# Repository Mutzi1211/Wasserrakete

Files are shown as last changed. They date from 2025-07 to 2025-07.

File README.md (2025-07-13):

# 🚀 Projektstruktur: Wasserrakete

Ein Überblick über alle Projektbestandteile – von CAD über Code bis zu Anforderungen und Abgaben.

---

### 📁 Abgabe/Poster
- 📄 **Projekt 2 Plakatvorstellung A2.pdf**  
  ➤ Das Poster für die offizielle Projektpräsentation.
---

### 📁 cad
3D-Modelle und technische Zeichnungen zur Rakete.

- 📁 **Rakete**  
 ➤ Enthält die CAD-Dateien des Raketenmodells  
  ➤ Dient zur Fertigung 

- 📄 **Rakete.pdf**  
  ➤ Zeichnung für die Rakete
---

### 📁 code
Die komplette Firmware für den Datenlogger (ESP32, SD-Logging, Webserver etc.)

---

### 📁 pcb
Alle Dateien zur Platine für den Datenlogger.

- 📁 **data_logger**  
  ➤ PCB-Design, dass alles auf einer Platine ist. Leider nicht mehr fertig geworden, aber wichtig für die Reproduktion

- 📁 **Prototyp**  
  ➤ Aktuelle Stand. Zusammengesteckt aus verschiedenen Bauteilen und auf einem 3D-Druck Boden montiert.

  - 📄 **Schaltplan.pdf**  
  ➤ Aktueller Schaltplan 

- 📄 **PCB.pdf**  
  ➤ Visualisierung der geplanten PCBs. 

- 📄 **Schematic.pdf**  
 ➤ Schematic des geplanten PCBs.

---

### 📁 Requirement Engineering
Projektplanung, Funktionsdefinitionen und Anforderungen.

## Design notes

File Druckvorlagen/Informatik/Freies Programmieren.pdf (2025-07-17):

Informatik | Freies Programmieren.docx | 1

Variante 3: Freies Programmieren
Aufgabe: Baue einen Datenlogger mit automatischer Fallschirmauslösung
Du erhältst ein fertiges Hardware-Modul mit den folgenden Bauteilen:
Bauteil | Funktion | Schnittstelle Steuerung | Betriebsspannung | Besonderheiten

ESP32

ICM-20948

BME280

Servo

Schalter Taster

LCD – Display

Deine Aufgabe:
Du sollst ein Programm für den ESP32 entwickeln, das:
1. Die Höhe der Rakete misst,
2. Daten (Höhe, Temperatur, Beschleunigung) während des Flugs aufzeichnet,
3. automatisch einen Fallschirm auslöst
4. den Systemstatus auf dem Display zeigt.

So gehst du vor:
Recherche
- Fülle die Tabelle oben aus. Recherchiere für jedes Bauteil:
- Funktion (Was macht es?)
- Schnittstelle (Wie kommuniziert es mit dem ESP32 ?) Vorgehensweise:
- Teil die Arbeit auf mehr Schulter auf: jeder fängt mit einem Sensor an
- Einzelne Komponenten programmieren
- Programmteile testen
- Ergebnisse validieren
- Herangehensweisen vergleichen

- Beste ausarbeiten und auf anderen Sensoren adaptieren
- Zu einem großen Teil zusammenführen
Sensoren testen
- In PlatformIO ein neues Projekt erstellen.
- Bibliotheken einbinden (z. B. SparkFun_BME280, ICM_20948, ServoESP32).
- Teste, ob die Sensoren Werte liefern.
Datenlogger programmieren
- Schreibe ein Programm, das Höhe, Temperatur und Beschleunigung regelmäßig misst.
- Speichere die Werte im CSV-Format auf der SD-Karte
Fallschirmauslösung
- Überwache den Höhenverlauf.
- Wie kann der perfekte Punkt zum Auslösen bestimmt werden? Display-Ausgabe
- Zeige z. B. aktuelle Höhe, Temperatur und Status ("Ready", "Recording", "Fallschirm ausgelöst") an.
Tests und Validierung
- Teste dein System am Boden und überprüfe:
- Löst der Fallschirm zuverlässig aus?
- Werden die Daten sinnvoll und im richtigen Format aufgezeichnet?
- Sind die Sensorwerte plausibel?
Hinweise:
- Verwende eine saubere setup()- und loop()-Struktur.
- Kapsle komplexe Funktionen (z. B. checkParachuteTrigger()).
- Kommentiere deinen Code verständlich.
- Denke an Sicherheit: Fallschirm darf nicht sich nicht zu früh oder zu spät öffnen
- ChatGPT oder andere KI-Modelle können helfen den Code zu kontrollieren oder bei Fehlern zu helfen – verwende sie nicht um das gesamte Problem zu lösen, sondern lass nur Teile programmieren

## Testen des Moduls

Nehmt euch das fertige Modul und überprüft, ob es wie gewünscht funktioniert. Beobachtet dabei insbesondere den Moment der Auslösung: Öffnet sich der Fallschirm genau dann, wenn ihr es erwartet habt? Überlegt euch mögliche Ursachen, wenn das Modul zu früh oder zu spät auslöst. Mögliche Fehlerquellen könnten sein:
- Ungenaue Sensordaten (z. B. Rauschen oder Verzögerungen)
- Fehlerhafte Berechnung der Höhe oder des Höhenabfalls
- Falsche Referenzwerte im Code
- Verzögerungen durch den Servo
Testet außerdem die Datenaufzeichnung auf der SD-Karte:
- Ist das Format korrekt? (z. B. CSV mit Kommas oder Semikolon getrennt)
- Stimmen die Einheiten? (z. B. Meter für Höhe, °C für Temperatur, hPa für Luftdruck)
- Sind die Messwerte in einer sinnvollen Größenordnung? (z. B. keine negativen Höhenwerte oder unrealistisch hohe Temperaturen)
Versucht, die aufgezeichneten Daten zu validieren:
- Ist der Verlauf der Höhe plausibel? Gibt es z. B. einen klar erkennbaren Anstieg beim Start und einen Abfall nach der höchsten Stelle?
- Entsprechen die Temperaturwerte etwa der Umgebungstemperatur?
- Verhält sich der Luftdruck physikalisch korrekt (z. B. sinkender Druck mit zunehmender Höhe)?
Diese Tests helfen euch, mögliche Fehler frühzeitig zu erkennen und die Funktion eures Systems zu verbessern.

## Aufzeichnen der Flugdaten

Für die Test empfehlen wir die Finnen 1 und die ogive Spitze. Die Flasche sollte mit 500ml Wasser gefüllt sein und bis 5 bar Luftdruck.
Jetzt wird’s spannend: Deine Rakete ist bereit für den Start – und dein Messmodul soll alle wichtigen Daten aufzeichnen! Höhe, Luftdruck, Temperatur und Bewegung geben dir spannende Einblicke in den Flugverlauf. Mit diesen Daten kannst du später genau analysieren, wann der höchste Punkt erreicht wurde, wie schnell die Rakete steigt – und ob der Fallschirm im richtigen Moment ausgelöst wurde.
Genaue Startanleitung in Plug-and-Play.
Hier ein Tutorial, wie man den Fallschirm richtig faltet, dass er
zuverlässig aufgeht.
https://www.youtube.com/shorts/kGTpw6yevmc?feature=share

Sicherheitshinweise
Bevor du mit dem Start beginnst, beachte folgende Punkte:
- Luftpumpe prüfen: Achte darauf, dass die Luftpumpe einen genau Anzeige hat. Die 5 Bar dürfen nicht überschritten werden.
- Zustand der Flasche prüfen: nach einigen Flügen können sich Risse am Hals der Flasche bilden. Außerdem wird die Flasche zunehmend dünner. Wechsle die Flasche nach 10 Starts aus.
- Sicherheitsabstand einhalten: Alle Zuschauer und Beteiligten müssen beim Start mindestens 5 m Abstand halten.
- Schutzbrille tragen: Bei Arbeiten mit Druckluft ist eine Schutzbrille Pflicht.
- Modul richtig befestigen: Das Modul muss mit der Flasche stabil verklebt sein, da diese sonst getrennt herunterfallen könnten.
- Startrampe nur auf freiem Gelände verwenden: Kein Start in der Nähe von Gebäuden, Straßen oder Stromleitungen. Empfehlung hierzu ist einer der kurzen Seiten eines Sportplatzes und leicht in die andere Richtung ausrichten. (maximal 20 Grad von der Senkrechten)
- Nie auf Menschen oder Tiere zielen: Die Rakete ist kein Spielzeug!
- Niemals die Rakete versuchen zu fangen.

## Analyse der Daten

Aufgabe: Auswertung der Flugdaten mit Excel
Für die Auswertung der Daten könnt euch für das Programm eure Wahl entscheiden. Bei Vorerfahrung kann Python mit dem Modul MathPlotLib eine Möglichkeit sein. Für den ersten Umgang mit Daten empfiehlt sich Excel.
Auswertung mit Excel:
1. CSV-Datei öffnen
- Starte Excel
- Öffne deine log_XXXX.csv-Datei
- Spaltenüberschriften umbenennen:
- Zeit [s], Höhe [m], Beschleunigung [g], Luftdruck [hPa], Temperatur [°C] etc
- Achte auf richtige Schreibweise (Excel verwendet Kommas für die Nachkommastellen, in der CSV Datei sind es Punkte – das Tool Suchen und Ersetzten kann helfen)
2. Höhe über Zeit – Diagramm erstellen
- Spalten „Zeit [s]“ und „Höhe [m]“ markieren
- Einfügen → Liniendiagramm
- Flugverlauf sichtbar machen
Arbeite aus den Daten folgende Wert heraus.
- Höchste Beschleunigung
- Apogäum
- Flugdauer
- Maximale Geschwindigkeit
- Sinkgeschwindigkeit
- Kann man daraus die Formel für den Senkrechten Wurf ausarbeiten?
- Bestimme den c_w Wert des Fallschirms (Masse, Luftdichte und Fläche gegeben)
- Bestimme die Schubkurve Wasserrakete – wie unterscheidet sie schon von großen Raketen bzw. Modellraketen mit Schwarzpulvermotor

## Daten präsentieren

Nachdem du deine Flugdaten ausgewertet hast, geht es nun darum, die Ergebnisse klar und verständlich darzustellen. Eine gute Präsentation hilft dabei, deine Messungen nachvollziehbar zu machen und besondere Erkenntnisse hervorzuheben. Übersichtliche Darstellung
- Erstelle eine strukturierte Auswertung in Excel oder PowerPoint.
- Nutze Tabellen für Werte wie Apogäum, Flugdauer, Maximalgeschwindigkeit etc.
- Verwende Diagramme, z. B.:
- Höhe über Zeit (für Flugkurve)
- Geschwindigkeit über Zeit
- Schubkurve
- Beschleunigung über Zei
Hebe Besonderheiten hervor
- Zeige deutlich, wo das Apogäum liegt
- Benenne Stellen mit besonderer Beschleunigung oder auffälligem Flugverhalten.
- Wenn der Fallschirm ausgelöst wurde: Markiere diesen Zeitpunkt (z. B. durch eine vertikale Linie im Diagramm).
- Was ist bei euren Daten besonders
- Gab es Probleme bei der Auswertung
Wenn jede Gruppe die gleichen Daten vorstellt, kann es schnell langweilig werden. Konzentriert euch auf die Erfolge oder Probleme, die ihr das Projekt hinweg hattet. Interpretation
Erkläre mit eigenen Worten:
- Was passiert wann?
- Warum sieht die Kurve so aus?
- Welche Phase des Flugs erkennst du (Start, Steigflug, Apogäum, Sinkflug)?
- Vergleiche berechnete Werte mit theoretischen Erwartungen (z. B. Höhe beim senkrechten Wurf).
Kreative Präsentationsform
- Erstelle ein kurzes Poster, ein Video mit Flug- und Datenanalyse oder einen digitalen Bericht.
- Baue Screenshots deiner Diagramme ein.
- Ergänze ein Fazit: Was würdest du beim nächsten Mal anders machen?
Ziel ist nicht nur, die Daten zu zeigen – sondern auch zu erklären, was sie bedeuten und was du daraus gelernt hast.

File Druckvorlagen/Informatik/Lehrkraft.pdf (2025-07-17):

Informatik | 1

## Informatik

## Programmierung:

Die Programmierung des Lernkoffers kann je nach Schulumgebung, Vorerfahrung der Schülerinnen und Schüler sowie verfügbarer Zeit im Unterricht auf drei unterschiedlichen Niveaus erfolgen. Jedes Niveau verfolgt ein eigenes Lernziel und adressiert unterschiedliche Kompetenzbereiche.
1. Plug-and-Play – Einstieg ohne Programmierkenntnisse
Zielgruppe:
Schülerinnen und Schüler ohne Vorerfahrung in der Programmierung.
Ausstattung:
Der Lernkoffer ist vollständig vorinstalliert. Beim Einschalten durchläuft der Bordcomputer automatisch einen Startprozess, bei dem alle Sensoren initialisiert und die Datenerfassung gestartet wird.
Mögliche Aufgabenstellungen:
- Beobachtung des Systemverhaltens: Welche Daten werden erfasst?
- Interpretation von Sensordaten im Webinterface (z. B. Beschleunigung, Höhe, Spannung)
- Exportieren und Auswerten der CSV-Daten am PC (z. B. in Excel, LibreOffice oder Python)
- Verständnisfragen: Was ist ein Sensor? Wie funktioniert ein Mikrocontroller?
- Physikalische Einordnung der Werte (z. B. Luftdruck ↔ Höhe)
Lernziele:
- Erste Begegnung mit digitalen Messsystemen
- Grundverständnis für Datenverarbeitung und Datenauswertung
- Förderung der Medienkompetenz ohne Einstieg in Programmiersyntax
2. Programmierung mit Unterstützung – Geführtes Lernen mit PlatformIO
Zielgruppe:
Schülerinnen und Schüler mit ersten Programmiererfahrungen oder technikaffine Gruppen.
Ausstattung:
Rechner mit Visual Studio Code (VS Code) und der PlatformIO-Erweiterung. Das Projekt wird bereitgestellt und kann geöffnet, angepasst und wieder auf den ESP32 hochgeladen werden.

Typische Inhalte und Aufgaben:
- Methoden anpassen: z. B. triggerParachute() nur bei bestimmtem Höhenabfall
- Sensorwerte filtern oder glätten (Moving Average, Schwellenwert)
- Neue Webinterface-Befehle implementieren (z. B. „Start Aufnahme“)
- LED oder Display-Ausgabe hinzufügen
- Logik für Messungen ändern (z. B. kürzere Intervalle, Schwellenwerte dynamisch setzen)
Lernziele:
- Verstehen von Methoden, Variablen und Bedingungen in C++
- Umgang mit Entwicklungsumgebungen (VS Code + PlatformIO)
- Erweitern bestehender Programme um eigene Ideen
- Teamarbeit beim Entwickeln und Testen
3. Selbst Programmieren – Freies Projekt für Fortgeschrittene
Zielgruppe:
Leistungsstarke oder besonders motivierte Schülerinnen und Schüler mit umfangreicher Vorerfahrung oder im Rahmen von Wahlkursen / Projekttagen.
Ausstattung:
Beliebige Entwicklungsumgebung (PlatformIO, Arduino IDE oder andere), Internetzugang zur Recherche.
Anforderungen:
- Selbständige Initialisierung der Sensoren über I2C/SPI
- Nutzung und Einbindung passender Bibliotheken (z. B. Adafruit, SparkFun)
- Strukturierung eines eigenen Programms: setup(), loop(), Klassenbildung
- Logging auf SD-Karte, Webinterface, OTA-Update (je nach Zielsetzung) Mögliche Projekte:
- Raketenflug vollständig selbst messen und analysieren
- Dashboards in Echtzeit gestalten
- Datenauswertung mit Python oder in der Cloud
- Kombination mehrerer Sensoren (z. B. BME280 + ICM20948) Lernziele:
- Selbstorganisiertes und forschendes Lernen
- Anwendung fortgeschrittener Programmierkonzepte
- Verstehen von Kommunikationsprotokollen und Datenformaten
- Problemlösestrategien und Debugging

Hinweis für Lehrkräfte:
Alle drei Stufen können auch parallel in einer Lerngruppe stattfinden. Die Lernkoffer bieten genug Flexibilität, um unterschiedliche Anforderungsniveaus zu bedienen und individuelle Lernpfade zu ermöglichen.

Hier ein Tutorial, wie man den Fallschirm richtig faltet, dass er zuverlässig aufgeht.
https://www.youtube.com/shorts/kGTpw6yevmc?feature=share

Eine genaue Startanleitung ist in „Plug-and-Play“ beschrieben.
Ansonsten gibt es eine kurze Videoanleitung unter: https://www.youtube.com/watch?v=_mfvzam6YKM&ab_channel=RaketfuedRockets

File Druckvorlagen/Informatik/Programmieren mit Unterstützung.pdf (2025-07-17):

Informatik | Programmieren mit Unterstützung.docx | 1

Variante 2: Programmierung mit Unterstützung
1. Überblick & Zielsetzung
Ziel:
Die Schüler entwickeln ein eigenes Programm für den Bordcomputer. Dieser soll:
- Sensordaten als Datenlogger aufzeichnen
- Bei Bedarf den Fallschirm auslösen
2. Komponenten verstehen
Verschaffe dir einen Überblick über alle Bauteile des Moduls. Nutze dazu den vereinfachten Schaltplan.
3. Rechercheaufgabe
In der Informatik kommunizieren Bauteile über sogenannte Schnittstellen (Interfaces). Um herauszufinden, wie die Sensoren funktionieren und wie man sie ansteuert, hilft eine gezielte Online-Recherche (z. B. mit den Begriffen „ESP32“ oder „Arduino“). Fülle die folgende Tabelle aus, indem du die Funktionen und Eigenschaften der Bauteile recherchierst:
Bauteil | Funktion | Schnittstelle Steuerung | Betriebsspannung | Besonderheiten

ESP32

ICM-20948

BME280

Servo

Schalter Taster

LCD – Display

Tipp: Oft hilft es, bei der Recherche Begriffe wie „ESP32“ oder „Arduino“ zu verwenden.

4. Schnittstellen & Spannungen verstehen
Initialisierung von Bauteilen – Warum ist das wichtig?
Bevor ein Mikrocontroller wie der ESP32 mit angeschlossenen Bauteilen arbeiten kann
(z. B. Sensoren, Servos oder Schalter), müssen diese im Programm initialisiert werden. Das bedeutet:
- Die Verbindung zwischen Mikrocontroller und Bauteil wird im Code festgelegt.
- Die Kommunikationseinstellungen (z. B. über welche Schnittstelle kommuniziert wird) werden definiert.
- Es wird geprüft, ob das Bauteil erkannt und funktionsfähig ist.
Warum ist das notwendig?
Ohne diese Initialisierung „weiß“ der ESP32 nicht, welches Gerät angeschlossen ist oder wie er mit diesem kommunizieren soll. Es ist vergleichbar mit einem Gerät, das angeschlossen wurde, aber nicht eingeschaltet oder konfiguriert wurde.
Was sind Schnittstellen?
Schnittstellen (auch „Interfaces“ genannt) sind digitale Verbindungsmöglichkeiten, über die zwei Geräte Daten austauschen können.
Wichtige Schnittstellen auf dem ESP32:
- I²C: Eine Bus-Schnittstelle für viele Sensoren über nur zwei Leitungen (SDA & SCL)
- SPI: Schnelle serielle Schnittstelle, ideal für SD-Karten oder Displays
- GPIO: Allgemeine Ein-/Ausgänge, z. B. für Taster, LEDs oder einfache Sensoren
- PWM: Pulsweitenmodulation – wird z. B. für Servos oder Helligkeitssteuerung genutzt

Beispiel: Der Sensor BME280 nutzt I²C – dafür muss man im Code angeben, an welchen Pins SDA (Datenleitung) und SCL (Taktleitung) angeschlossen sind.

Typische Spannungen:
- 3,3 V: Die meisten Sensoren für den ESP32
- 5,0 V: Häufig bei Arduino Uno oder bei Servos
Achtung: Der ESP32 arbeitet intern mit 3,3 V. Bauteile, die mit 5 V kommunizieren, brauchen oft einen Pegelwandler!
Zusammengefasst:
- Initialisierung: Der ESP32 muss wissen, welches Gerät da ist und wie man es anspricht.

- Schnittstellen: Jede Bauteilart spricht eine eigene Sprache (z. B. I²C, SPI, PWM…)
- Spannung: Zu hohe Spannung zerstört Bauteile – zu wenig Spannung verhindert Funktion
5. Programmaufbau verstehen
Der ESP32 führt Programme in einer festen Reihenfolge aus.
Er startet immer mit: | Dann läuft dauerhaft:

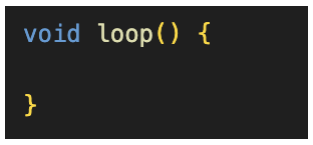
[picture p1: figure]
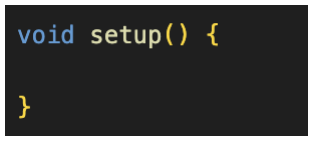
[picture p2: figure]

Zur Erleichterung sind bereits Bereiche vordefiniert, die zu bestimmten Zeitpunkten aufgerufen werden. (Sind mit Kommentaren markiert)
Typischer Aufbau:
Programmbereich | Aufgabe
setup() | Einmalige Aufgaben Komponenten initialisieren (.init() Methoden)
loop() | Wiederkehrende Aufgaben Daten aufzeichnen, Fallschirm-Bedingung prüfen
6. Klassendiagramm & Methoden
Alle Sensoren sind als Klassen implementiert. Die Methoden zur Initialisierung und Abfrage sind standardisiert.
Hinweis: Initialisierungen geben einen booleschen Wert zurück (true bei Erfolg). Beispielmethoden:
- bool initSensor()
- float getAltitude()
- bool initWebserver()
7. Erweiterung: Webinterface
Optional kann der ESP32 eine Webseite bereitstellen, um Live-Daten anzuzeigen. Dafür wird die Methode initWebserver() verwendet.

8. Programmablauf planen
Erstelle ein Flussdiagramm, das den Ablauf deines Programms beschreibt.
Dein Auftrag:
- Entwickle allein ein Flussdiagramm zum Ablauf eures Raketenprogramms.
- Tauscht euch danach in der Gruppe aus.
- Diskutiert Vor- und Nachteile eurer Lösungen.
Als Beispiel für ein Flussdiagramm hier ein potenzieller Ablauf von Spaghetti essen.
9. Diskussionspunkte

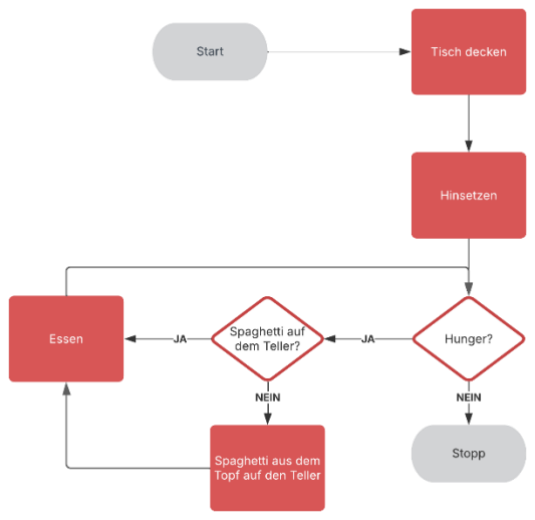
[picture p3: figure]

- Was passiert, wenn ein Sensor nicht erkannt wird?
- Was, wenn die SD-Karte fehlt oder voll ist?
- Wie könnt ihr Fehler erkennen und melden?
10. Umsetzung auf dem ESP32
Lade das Programm über PlatformIO auf den ESP32. Arbeite nur in der Datei main.cpp (im src-Ordner). Verwende ausschließlich die vordefinierten Methoden. (s. letztes Blatt)
11. Wie wird der Fallschirm ausgelöst?
Entscheide dich für eine oder mehrere Bedingungen:
- Höhenabfall größer als X m?
- Hohe Beschleunigung?
- Drehbewegung (Gyroskop)?
→ entwickle ein detailliertes Flussdiagramm für die Fallschirmauslösung (Vorschlag auf der nächsten Seite)

Vergleicht euer Ergebnis mit dem Vorschlag. Stellt Vor- Nachteile eure Lösung im Vergleich zum Vorschlag dar. Ein paar weiter Diskussionspunkte:
- Warum mehr als 0.1 Meter unter höchster Höhe
- Warum 10 Sekunden warten?
- Warum die Gesamt-beschleunigung?
- Wo würde man einfügen die geflogene Höhe auf dem Display anzuzeigen?
12. Anschluss & Verdrahtung

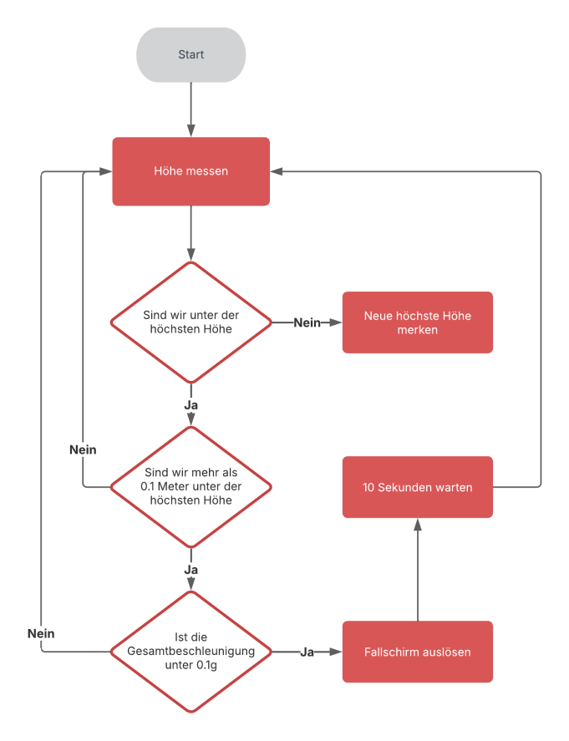
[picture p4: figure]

Nutze den Schaltplan, um die Pinbelegung nachzuvollziehen.
Die richtige Verdrahtung ist Voraussetzung für eine funktionierende Programmierung.

## Testen des Moduls

Nehmt euch das fertige Modul und überprüft, ob es wie gewünscht funktioniert. Beobachtet dabei insbesondere den Moment der Auslösung: Öffnet sich der Fallschirm genau dann, wenn ihr es erwartet habt? Überlegt euch mögliche Ursachen, wenn das Modul zu früh oder zu spät auslöst. Mögliche Fehlerquellen könnten sein:
- Ungenaue Sensordaten (z. B. Rauschen oder Verzögerungen)
- Fehlerhafte Berechnung der Höhe oder des Höhenabfalls
- Falsche Referenzwerte im Code
- Verzögerungen durch den Servo
Testet außerdem die Datenaufzeichnung auf der SD-Karte:
- Ist das Format korrekt? (z. B. CSV mit Kommas oder Semikolon getrennt)
- Stimmen die Einheiten? (z. B. Meter für Höhe, °C für Temperatur, hPa für Luftdruck)
- Sind die Messwerte in einer sinnvollen Größenordnung? (z. B. keine negativen Höhenwerte oder unrealistisch hohe Temperaturen)
Versucht, die aufgezeichneten Daten zu validieren:
- Ist der Verlauf der Höhe plausibel? Gibt es z. B. einen klar erkennbaren Anstieg beim Start und einen Abfall nach der höchsten Stelle?
- Entsprechen die Temperaturwerte etwa der Umgebungstemperatur?
- Verhält sich der Luftdruck physikalisch korrekt (z. B. sinkender Druck mit zunehmender Höhe)?
Diese Tests helfen euch, mögliche Fehler frühzeitig zu erkennen und die Funktion eures Systems zu verbessern.

## Aufzeichnen der Flugdaten

Für die Test empfehlen wir die Finnen 1 und die ogive Spitze. Die Flasche sollte mit 500ml Wasser gefüllt sein und bis 5 bar Luftdruck.
Jetzt wird’s spannend: Deine Rakete ist bereit für den Start – und dein Messmodul soll alle wichtigen Daten aufzeichnen! Höhe, Luftdruck, Temperatur und Bewegung geben dir spannende Einblicke in den Flugverlauf. Mit diesen Daten kannst du später genau analysieren, wann der höchste Punkt erreicht wurde, wie schnell die Rakete steigt – und ob der Fallschirm im richtigen Moment ausgelöst wurde.
Genaue Startanleitung in Plug-and-Play.
Hier ein Tutorial, wie man den Fallschirm richtig faltet, dass er
zuverlässig aufgeht.
https://www.youtube.com/shorts/kGTpw6yevmc?feature=share

Sicherheitshinweise
Bevor du mit dem Start beginnst, beachte folgende Punkte:
- Luftpumpe prüfen: Achte darauf, dass die Luftpumpe einen genau Anzeige hat. Die 5 Bar dürfen nicht überschritten werden.
- Zustand der Flasche prüfen: nach einigen Flügen können sich Risse am Hals der Flasche bilden. Außerdem wird die Flasche zunehmend dünner. Wechsle die Flasche nach 10 Starts aus.
- Sicherheitsabstand einhalten: Alle Zuschauer und Beteiligten müssen beim Start mindestens 5 m Abstand halten.
- Schutzbrille tragen: Bei Arbeiten mit Druckluft ist eine Schutzbrille Pflicht.
- Modul richtig befestigen: Das Modul muss mit der Flasche stabil verklebt sein, da diese sonst getrennt herunterfallen könnten.
- Startrampe nur auf freiem Gelände verwenden: Kein Start in der Nähe von Gebäuden, Straßen oder Stromleitungen. Empfehlung hierzu ist einer der kurzen Seiten eines Sportplatzes und leicht in die andere Richtung ausrichten. (maximal 20 Grad von der Senkrechten)
- Nie auf Menschen oder Tiere zielen: Die Rakete ist kein Spielzeug!
- Niemals die Rakete versuchen zu fangen.

## Analyse der Daten

Aufgabe: Auswertung der Flugdaten mit Excel
Für die Auswertung der Daten könnt euch für das Programm eure Wahl entscheiden. Bei Vorerfahrung kann Python mit dem Modul MathPlotLib eine Möglichkeit sein. Für den ersten Umgang mit Daten empfiehlt sich Excel.
Auswertung mit Excel:
1. CSV-Datei öffnen
- Starte Excel
- Öffne deine log_XXXX.csv-Datei
- Spaltenüberschriften umbenennen:
- Zeit [s], Höhe [m], Beschleunigung [g], Luftdruck [hPa], Temperatur [°C] etc
- Achte auf richtige Schreibweise (Excel verwendet Kommas für die Nachkommastellen, in der CSV Datei sind es Punkte – das Tool Suchen und Ersetzten kann helfen)
2. Höhe über Zeit – Diagramm erstellen
- Spalten „Zeit [s]“ und „Höhe [m]“ markieren
- Einfügen → Liniendiagramm
- Flugverlauf sichtbar machen
Arbeite aus den Daten folgende Wert heraus.
- Höchste Beschleunigung
- Apogäum
- Flugdauer
- Maximale Geschwindigkeit
- Sinkgeschwindigkeit
- Kann man daraus die Formel für den Senkrechten Wurf ausarbeiten?
- Bestimme den c_w Wert des Fallschirms (Masse, Luftdichte und Fläche gegeben)
- Bestimme die Schubkurve Wasserrakete – wie unterscheidet sie schon von großen Raketen bzw. Modellraketen mit Schwarzpulvermotor

## Daten präsentieren

Nachdem du deine Flugdaten ausgewertet hast, geht es nun darum, die Ergebnisse klar und verständlich darzustellen. Eine gute Präsentation hilft dabei, deine Messungen nachvollziehbar zu machen und besondere Erkenntnisse hervorzuheben. Übersichtliche Darstellung
- Erstelle eine strukturierte Auswertung in Excel oder PowerPoint.
- Nutze Tabellen für Werte wie Apogäum, Flugdauer, Maximalgeschwindigkeit etc.
- Verwende Diagramme, z. B.:
- Höhe über Zeit (für Flugkurve)
- Geschwindigkeit über Zeit
- Schubkurve
- Beschleunigung über Zeit
Hebe Besonderheiten hervor
- Zeige deutlich, wo das Apogäum liegt
- Benenne Stellen mit besonderer Beschleunigung oder auffälligem Flugverhalten.
- Wenn der Fallschirm ausgelöst wurde: Markiere diesen Zeitpunkt (z. B. durch eine vertikale Linie im Diagramm).
- Was ist bei euren Daten besonders
- Gab es Probleme bei der Auswertung
Wenn jede Gruppe die gleichen Daten vorstellt, kann es schnell langweilig werden. Konzentriert euch auf die Erfolge oder Probleme, die ihr das Projekt hinweg hattet. Interpretation
Erkläre mit eigenen Worten:
- Was passiert wann?
- Warum sieht die Kurve so aus?
- Welche Phase des Flugs erkennst du (Start, Steigflug, Apogäum, Sinkflug)?
- Vergleiche berechnete Werte mit theoretischen Erwartungen (z. B. Höhe beim senkrechten Wurf).
Kreative Präsentationsform
- Erstelle ein kurzes Poster, ein Video mit Flug- und Datenanalyse oder einen digitalen Bericht.
- Baue Screenshots deiner Diagramme ein.
- Ergänze ein Fazit: Was würdest du beim nächsten Mal anders machen?
Ziel ist nicht nur, die Daten zu zeigen – sondern auch zu erklären, was sie bedeuten und was du daraus gelernt hast.

Methoden

Methoden | Funktion
init() | Starte die Protokolle für SD-Karte und Sensoren
initWebserver() | Starte Webserver und WLAN
initRecording() | Legt die CSV - Datei an
record() | Legt die aktuellen Werte auf der SD-Karte ab
check_parachute() | Gibt true zurück, wenn der Fallschirm auslösen soll
deploy_parachute() | Löst den Pin für Fallschirm aus Sollte wieder eingefahren werden
stop_parachute() | Fährt den Pin des Fallschirms wieder aus
reset() | Setzt die Daten für die Fallschirmauslösung zurück

Alle Komponenten müssen mit .init() aufgerufen werden und deren Status in die dazugehörige Variable gespeichert werden.
Bsp:
bme_active = bme.init();

Dies gilt für:
- icm
- bme
- lipo
- oled
- servo

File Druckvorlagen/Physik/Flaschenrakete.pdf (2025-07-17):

Physik | Flaschenrakete.docx | 1

# Aufbau der Flaschenrakete

## Grundprinzip Aerodynamik (Schwerpunkt & Druckpunkt):

Die Aerodynamik kleiner Raketen (z. B. Modellraketen) beruht im Wesentlichen auf dem Zusammenspiel von Schwerpunkt (Massenmittelpunkt der Rakete) und Druckpunkt (Angriffspunkt der resultierenden aerodynamischen Kräfte). Diese bestimmen die Flugstabilität.

Eine Passive Flugstabilisierung ist bei jeder Rakete anzustreben. Dies ist gegeben, sobald der Schwerpunkt in Flugrichtung vor dem Druckpunkt liegt. Der Abstand zwischen SP und DP sollte ca. 1– 2 Kaliber (Raketendurchmesser) betragen.

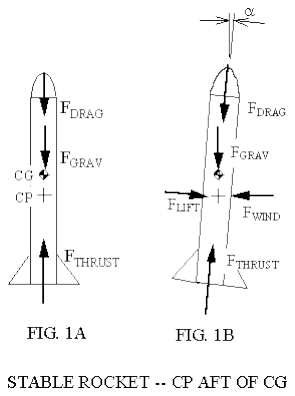
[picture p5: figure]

## Warum Finnen?

Generell funktionieren Finnen, indem sie, wenn die Rakete leicht von der Flugrichtung abweicht, ein Luftstrom schräg auf die Finnen trifft. Dies erzeugt eine aerodynamische Rückstellkraft um den Schwerpunkt, welche der Störung entgegenwirkt.

Wir nutzen Finnen am Ende der Rakete, selbst mit einer Passiven Stabilisierung, um die Flugbahn auch in dem Bereich des Fluges kontrolliert zu halten, der für eine passive Stabilisierung durch Schwerpunkt und Druckpunkt noch nicht schnell genug ist, bzw. nicht genug Luftstrom bietet.

Abbildung 1: Stable Rocket
Quelle: https://antwortenhier.me/q/stabilitaet-der-rakete-waehrend-des-fluges-warum-aendert-die-auftriebskraft-143452964425

## Wie viele Finnen?

Weniger als drei Finnen bieten keine vollständige seitliche Abdeckung und führen zu Instabilität oder unkontrollierter Rollbewegung. Mehr als drei, etwa vier oder fünf Finnen, abgesehen der höheren Massenkalkulation, erhöhen den Luftwiderstand deutlich, was zu einem geringeren Apogäum führt und die Effizienz verschlechtert. Außerdem verlagern zusätzliche Finnen den Massenschwerpunkt weiter nach hinten, was die Stabilitätsreserve reduziert, wenn nicht durch zusätzliches Frontgewicht kompensiert wird.

## Aerodynamik Spitzenformen

Die Form der Raketenspitze hat großen Einfluss auf die Aerodynamik, insbesondere auf den Luftwiderstand und das Flugverhalten bei unterschiedlichen Geschwindigkeiten. Bei langsamen Flügen im Unterschallbereich sind rundlichere, stromlinienförmige Nasen (z.B. ogivale oder elliptische Spitzen) besonders vorteilhaft, da sie die Luft sanft verdrängen und somit den Druckwiderstand minimieren.

Im Überschallbereich ändern sich das Ganze. Hier dominieren Stoßwellen den Luftwiderstand und spitze, langgezogene Formen (z.B. Kegelnase, von Kármán-Profile oder Haack-Profile) sind vorteilhaft, da sie die Stoßwellen effizient ableiten und damit der Wellenwiderstand reduziert wird. Raketenspitzen sorgen für effiziente Strömungsführung und sind daher essenziell zu optimieren.

Zu berechnen ist der Luftwiderstand aus Luftdichte, Beschleunigung, Stirnfläche und Widerstandsbeiwert der Hauptsächlich durch die Spitze bestimmt wird.

FD =

1
2

⋅ ρ ⋅ v

2
⋅ Cd ⋅ A

## Andere Aerodynamikaspekte

Weitere wichtige Aspekte sind der asymmetrische Luftstrom bei z.B. Seitenwind oder einem (präferierten) schrägen Start, da die Rakete driften, kippen oder rotieren kann, falls nicht genug Stabilisierung vorliegt. Ein Launchrail ist daher essenziell. Wichtig ist aus das Einbeziehen von „Roll“.

Bei schräger Montierung der Finnen rotiert die Rakete um die Längsachse in einen „Drall“. Dieser kann zwar stabilisierend wirken, kann aber auch durch harmonisches Schwingen die Rakete aus der Stabilität reißen und Probleme bei der Sensorik verursachen.

Der „Aftcone“ der Rakete, als das Heck ist auch sehr bedeutend für das Flugverhalten, da ohne aerodynamische Optimierung ein starker Unterdruckbereich oder „Nachlauf“ hinter der Rakete entsteht, welcher einen signifikanten Widerstand mit sich zieht.

Weitere Einflüsse haben zum Beispiel Oberfläche der Rakete (sog. „Skin Friction“) durch Luftreibung, Übergange zwischen Modulen oder Stufen (zum Beispiel durch Geometrieänderung) durch Turbulenzen und Verwirbelungen und das Verhältnis von Länge zu Durchmesser, da längere Raketen aerodynamisch durch weniger Richtungsänderung des Luftstroms wesentlich günstiger sind.

Wie könnte man die Wasserrakete optimieren. Fehlen der Startrampe wichtige Features?

## Fallschirmauslegung

Für die Sinkgeschwindigkeit und die Fallschirm-Mindestgröße benötigen wir primär die Bremswirkung.

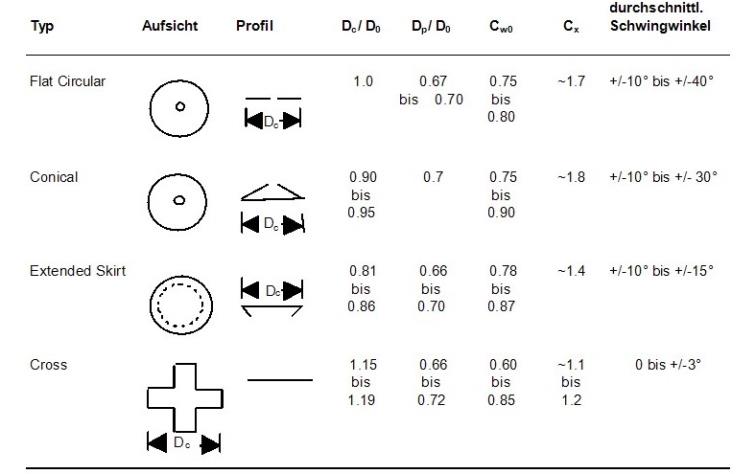
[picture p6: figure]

Die Bremskraft berechnet sich laut Theo W. Knacke („Parachute Recovery Systems“) aus Luftwiderstandsbeiwert, der Fläche des Fallschirms, der Fluggeschwindigkeit und der Luftdichte. Eine Tabelle aus dem Buch beschreibt die unterschiedlichen Bauformen mit deren CW-Beiwert auf. Eine annähernde Berechnung ist wie folgt möglich.

Fbrems = cw ⋅ A ⋅

ρ
2

⋅ v

2

In unserem Falle beträgt cW 0,75 bis 0,8

Durch Gleichsetzen mit der Formel für die Gewichtskraft kommt man auf die Formel für die Sinkgeschwindigkeit:

Vsink = √
2 ⋅ m ⋅ g
A ⋅ cw ⋅ ρ

Durch Einsetzen der Erwünschten Sinkgeschwindigkeit kann man die Fallschirmfläche/Durchmesser berechnen.

Die Schockbelastung lässt sich mithilfe des „Opening Force Coefficient“ Cx aus besagter Tabelle (Siehe Knacke S.5) einfach berechnen.

FSchock = FBrems ⋅ Cx

In unserem Falle beträgt Cx ca. 1,7. Das heißt die entstehende Kraft bei Öffnung entspricht dem 1,7-fachen der Bremskraft.

Berechne den Durchmesser des Fallschirms, wenn die Rakete eine maximale Fallgeschwindigkeit von 5m/s bzw. 4m/s erreichen soll.

## Fallschirmauswurf

Rechercheaufgabe:

Informiert dich in Einzelarbeit über die verschiedenen Methoden des Fallschirmauswurfes. Stellt Vor-und Nachteile im Team vor und legt euch auf eine Möglichkeit fest. Vergleicht dabei große Raketen, Modellraketen und Wasserraketen. Arbeitet für jeden Raketentyp die für euch beste Variante aus.

Bei unserer Wasserrakete haben wir uns für einen Mechanismus entschieden, der den Fallschirm beim Aufklappen der Spitze freigibt. Der Vorteil daran ist, dass die Spitze relativ kurz ist, da wir den Hohlraum der Spitze ausgenutzt wird.

## Wassermenge Flasche

Die optimale Wassermenge in einer Flaschenrakete liegt typischerweise bei ca. 1/3 bis 1/2 des Flaschenvolumens. In diesem Bereich entsteht das beste Verhältnis zwischen Schub und „Brenndauer“: Das Wasser wirkt als Reaktionsmasse und wird vom komprimierten Luftdruck ausgestoßen, wobei Schub erzeugt wird. Je mehr Wasser, desto größer die Masse zum Beschleunigen aber desto weniger Luft steht zur Verfügung, um Druck aufzubauen und Volumen zu expandieren. Umgekehrt bringt zu wenig Wasser zwar viel Gasvolumen, aber zu wenig Masse für effektiven Schub. Der Sweet Spot liegt meist bei ca. 35–40 % Füllstand, abhängig von Düsenform und Druck.

Zu viel Wasser kann sogar kontraproduktiv sein. Die Rakete wird schwer, beschleunigt langsamer und erreicht geringere Höhen, weil der Druck schnell nachlässt. Zu wenig Wasser führt zu kurzen Schubphasen mit geringem Impuls.

Wichtig ist, dass das Verhältnis zwischen komprimierbarem Gasraum und Ausstoßmasse im Gleichgewicht ist.

## Massenbudget

Das Massenbudget einer Wasserrakete ermittelst du optimal, indem du zuerst die Masse der Hauptkomponenten festlegst: Flasche, Wasser, Luftdruck und Zusatzausrüstung wie Fallschirm, Verschluss oder Stabilisatoren. Wichtig ist, das Verhältnis zwischen Treibmittelmasse (Wasser) und Strukturmasse so zu optimieren, dass genug Wasser für Schub vorhanden ist, ohne die Rakete unnötig schwer zu machen. Dabei hilft die Faustregel, etwa 30–40 % des Flaschenvolumens mit Wasser zu füllen, während das Restvolumen mit komprimierter Luft gefüllt wird.

Um das optimale Massenbudget zu bestimmen, kannst du experimentell verschiedene Wasserfüllmengen und Gewichte der Zusatzelemente testen oder numerische Simulationen verwenden.

## OpenRocket

OpenRocket ist eine kostenlose Open-Source-Software, mit der man Modellraketen entwerfen, simulieren und analysieren kann – noch bevor man sie baut. Eure Aufgabe ist es, die Wasserrakete nachzubauen und den Flug zu simulieren.

1. Design

Bau die Rakete bis auf ihre Bestandteile auseinander und versuche die Maße so exakt wie möglich zu übernehmen. Achte darauf, dass keine Sprünge zwischen Bauteilen sind. OpenRocket kann damit nicht so gut umgehen. Wiege die Teile einzeln und passe sie in OpenRocket (für jeden Element unter dem Reiter „Werte überschreiben“).

2. Analyse

Bei gebauter Rakete wird der Druckpunkt rot und der Schwerpunkt blau-weiß angezeigt. Vergleiche das mit den Grundprinzipien der Aerodynamik. Wie könnte man die Punkte optimieren? Versuche auch den Schwerpunkt der echten Rakete zu bestimmen. Warum könnte es dabei zu Abweichungen kommen?

3. Simulation

OpenRocket unterstützt nicht direkt die Simulation von Wasserraketen, sondern für Feststoffmotoren. Um trotzdem die Rakete zu simulieren, müsst ihr die Schubkurve (Datei mit .eng-Endung) in den Einstellungen importieren. Unter dem Reiter „Simulation“ kann man eine neue erstellen und exportieren. Speichert die Daten, um sie mit den echten Daten zu vergleichen.

## Testen des Moduls

Nehmt euch das fertige Modul und überprüft, ob es wie gewünscht funktioniert. Beobachtet dabei insbesondere den Moment der Auslösung: Öffnet sich der Fallschirm genau dann, wenn ihr es erwartet habt? Überlegt euch mögliche Ursachen, wenn das Modul zu früh oder zu spät auslöst. Mögliche Fehlerquellen könnten sein:

- Ungenaue Sensordaten (z. B. Rauschen oder Verzögerungen)
- Fehlerhafte Berechnung der Höhe oder des Höhenabfalls
- Falsche Referenzwerte im Code
- Verzögerungen durch den Servo
- Testet außerdem die Datenaufzeichnung auf der SD-Karte:
- Ist das Format korrekt? (z. B. CSV mit Kommas oder Semikolon getrennt)
- Stimmen die Einheiten? (z. B. Meter für Höhe, °C für Temperatur, hPa für Luftdruck)
- Sind die Messwerte in einer sinnvollen Größenordnung? (z. B. keine negativen Höhenwerte oder unrealistisch hohe Temperaturen)

Versucht, die aufgezeichneten Daten zu validieren:

- Ist der Verlauf der Höhe plausibel? Gibt es z. B. einen klar erkennbaren Anstieg beim Start und einen Abfall nach der höchsten Stelle?
- Entsprechen die Temperaturwerte etwa der Umgebungstemperatur?
- Verhält sich der Luftdruck physikalisch korrekt (z. B. sinkender Druck mit zunehmender Höhe)?

Diese Tests helfen euch, mögliche Fehler frühzeitig zu erkennen und die Funktion eures Systems zu verbessern.

## Aufzeichnen der Flugdaten

Für die Test empfehlen wir die Finnen 1 und die ogive Spitze. Die Flasche sollte mit 500ml Wasser gefüllt sein und bis 5 bar Luftdruck.

Jetzt wird’s spannend: Deine Rakete ist bereit für den Start – und dein Messmodul soll alle wichtigen Daten aufzeichnen! Höhe, Luftdruck, Temperatur und Bewegung geben dir spannende Einblicke in den Flugverlauf. Mit diesen Daten kannst du später genau analysieren, wann der höchste Punkt erreicht wurde, wie schnell die Rakete steigt – und ob der Fallschirm im richtigen
Moment ausgelöst wurde.

Hier ein Tutorial, wie man den Fallschirm richtig faltet, dass er zuverlässig aufgeht.

https://www.youtube.com/shorts/kGTpw6yevmc?feature=share

## Sicherheitshinweise

- Bevor du mit dem Start beginnst, beachte folgende Punkte:
- Luftpumpe prüfen: Achte darauf, dass die Luftpumpe einen genau Anzeige hat. Die 5 Bar dürfen nicht überschritten werden.
- Zustand der Flasche prüfen: nach einigen Flügen können sich Risse am Hals der Flasche bilden. Außerdem wird die Flasche zunehmend dünner. Wechsle die Flasche nach 10 Starts aus.
- Sicherheitsabstand einhalten: Alle Zuschauer und Beteiligten müssen beim Start mindestens 5 m Abstand halten.
- Schutzbrille tragen: Bei Arbeiten mit Druckluft ist eine Schutzbrille Pflicht.
- Modul richtig befestigen: Das Modul muss mit der Flasche stabil verklebt sein, da diese sonst getrennt herunterfallen könnten.
- Startrampe nur auf freiem Gelände verwenden: Kein Start in der Nähe von Gebäuden, Straßen oder Stromleitungen. Empfehlung hierzu ist einer der kurzen Seiten eines Sportplatzes und leicht in die andere Richtung ausrichten. (maximal 20 Grad von der Senkrechten)
- Nie auf Menschen oder Tiere zielen: Die Rakete ist kein Spielzeug!
- Niemals die Rakete versuchen zu fangen.

## Analyse der Daten

### Aufgabe: Auswertung der Flugdaten mit Excel

Für die Auswertung der Daten könnt euch für das Programm eure Wahl entscheiden. Bei Vorerfahrung kann Python mit dem Modul MathPlotLib eine Möglichkeit sein. Für den ersten Umgang mit Daten empfiehlt sich Excel.

Auswertung mit Excel:

1. CSV-Datei öffnen
- Starte Excel
- Öffne deine log_XXXX.csv-Datei
- Spaltenüberschriften umbenennen:
- Zeit [s], Höhe [m], Beschleunigung [g], Luftdruck [hPa], Temperatur [°C] etc
- Achte auf richtige Schreibweise (Excel verwendet Kommas für die Nachkommastellen, in der CSV Datei sind es Punkte – das Tool Suchen und Ersetzten kann helfen)
2. Höhe über Zeit – Diagramm erstellen
- Spalten „Zeit [s]“ und „Höhe [m]“ markieren
- Einfügen → Liniendiagramm
- Flugverlauf sichtbar machen
- Arbeite aus den Daten folgende Wert heraus.
- Höchste Beschleunigung
- Apogäum
- Flugdauer
- Maximale Geschwindigkeit
- Sinkgeschwindigkeit
- Kann man daraus die Formel für den Senkrechten Wurf ausarbeiten?
- Bestimme den c_w Wert des Fallschirms (Masse, Luftdichte und Fläche gegeben)
- Bestimme die Schubkurve Wasserrakete – wie unterscheidet sie schon von großen Raketen bzw. Modellraketen mit Schwarzpulvermotor

## Daten präsentieren

Nachdem du deine Flugdaten ausgewertet hast, geht es nun darum, die Ergebnisse klar und verständlich darzustellen. Eine gute Präsentation hilft dabei, deine Messungen nachvollziehbar zu machen und besondere Erkenntnisse hervorzuheben.

Übersichtliche Darstellung

- Erstelle eine strukturierte Auswertung in Excel oder PowerPoint.
- Nutze Tabellen für Werte wie Apogäum, Flugdauer, Maximalgeschwindigkeit etc.
- Verwende Diagramme, z. B.:
- Höhe über Zeit (für Flugkurve)
- Geschwindigkeit über Zeit
- Schubkurve
- Beschleunigung über Zeit

Hebe Besonderheiten hervor

- Zeige deutlich, wo das Apogäum liegt
- Benenne Stellen mit besonderer Beschleunigung oder auffälligem Flugverhalten.
- Wenn der Fallschirm ausgelöst wurde: Markiere diesen Zeitpunkt (z. B. durch eine vertikale Linie im Diagramm).
- Was ist bei euren Daten besonders
- Gab es Probleme bei der Auswertung

Wenn jede Gruppe die gleichen Daten vorstellt, kann es schnell langweilig werden. Konzentriert euch auf die Erfolge oder Probleme, die ihr das Projekt hinweg hattet.

Interpretation

Erkläre mit eigenen Worten:

- Was passiert wann?
- Warum sieht die Kurve so aus?
- Welche Phase des Flugs erkennst du (Start, Steigflug, Apogäum, Sinkflug)?
- Vergleiche berechnete Werte mit theoretischen Erwartungen (z. B. Höhe beim senkrechten Wurf).

Kreative Präsentationsform

- Erstelle ein kurzes Poster, ein Video mit Flug- und Datenanalyse oder einen digitalen Bericht.
- Baue Screenshots deiner Diagramme ein.
- Ergänze ein Fazit: Was würdest du beim nächsten Mal anders machen?

Ziel ist nicht nur, die Daten zu zeigen – sondern auch zu erklären, was sie bedeuten und was du daraus gelernt hast.

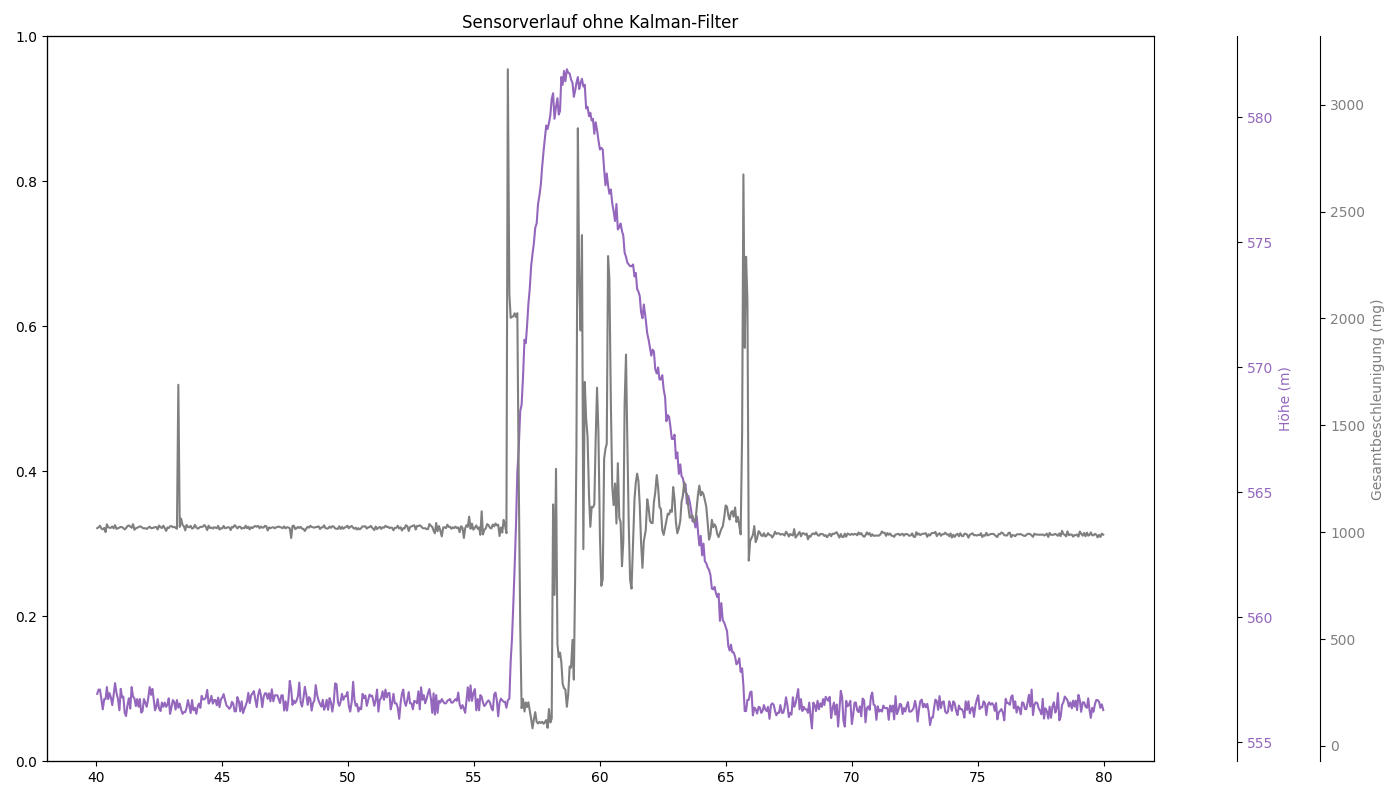
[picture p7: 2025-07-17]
code/Auswertung/Figure_2.png

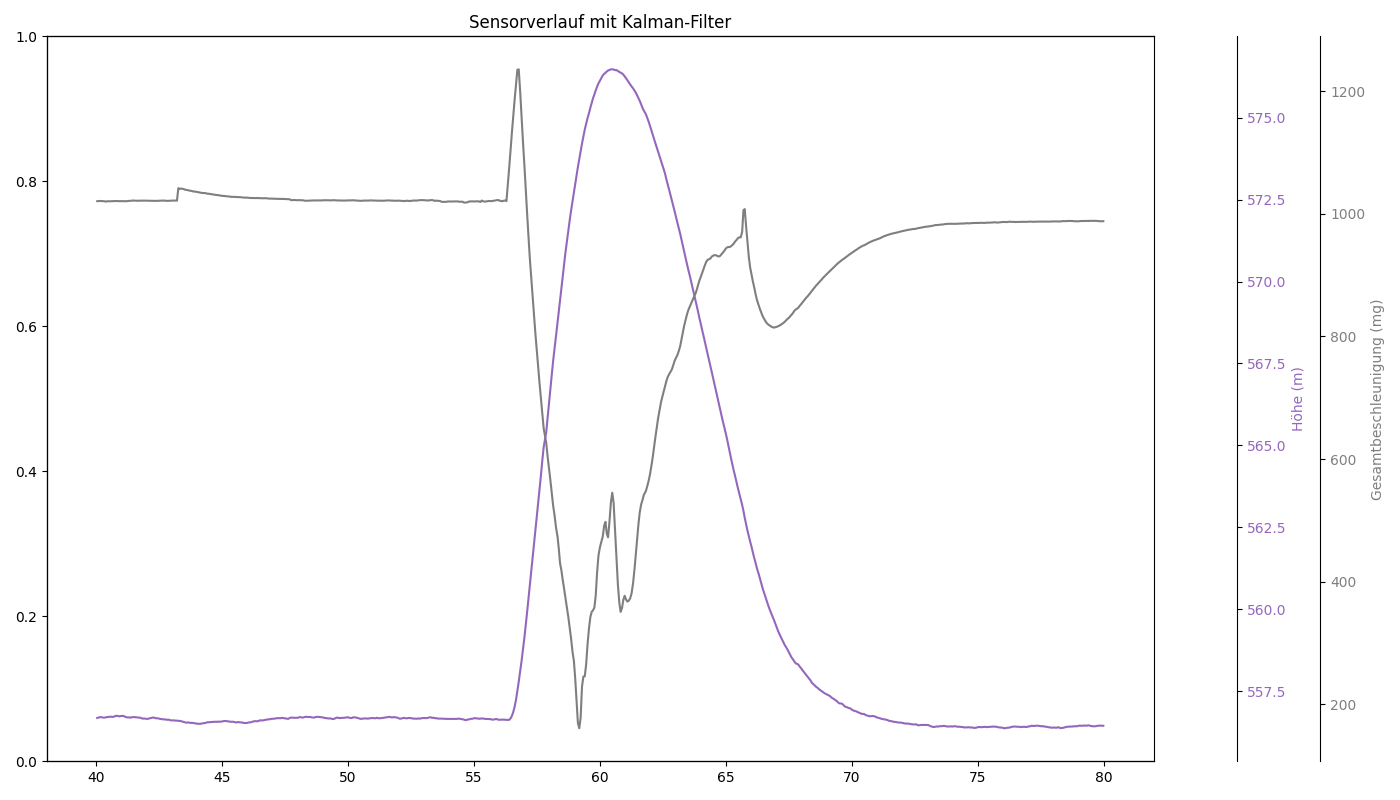
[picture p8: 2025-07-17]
code/Auswertung/Figure_1.png

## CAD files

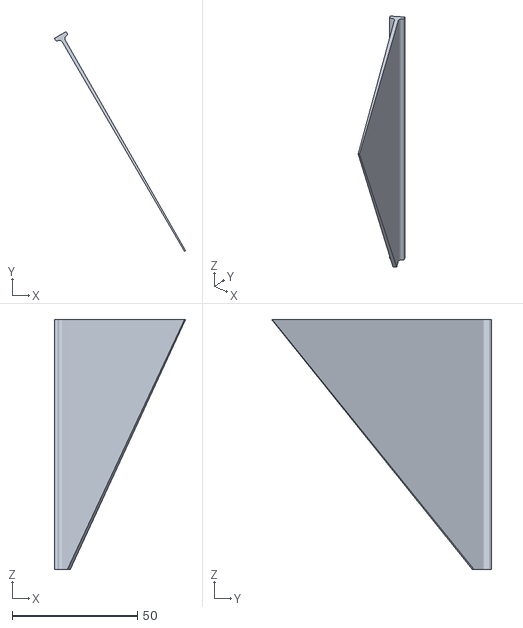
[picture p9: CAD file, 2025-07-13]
cad/Rakete/Rakete - Finne3.stl
52.5 x 87.9 x 100.0

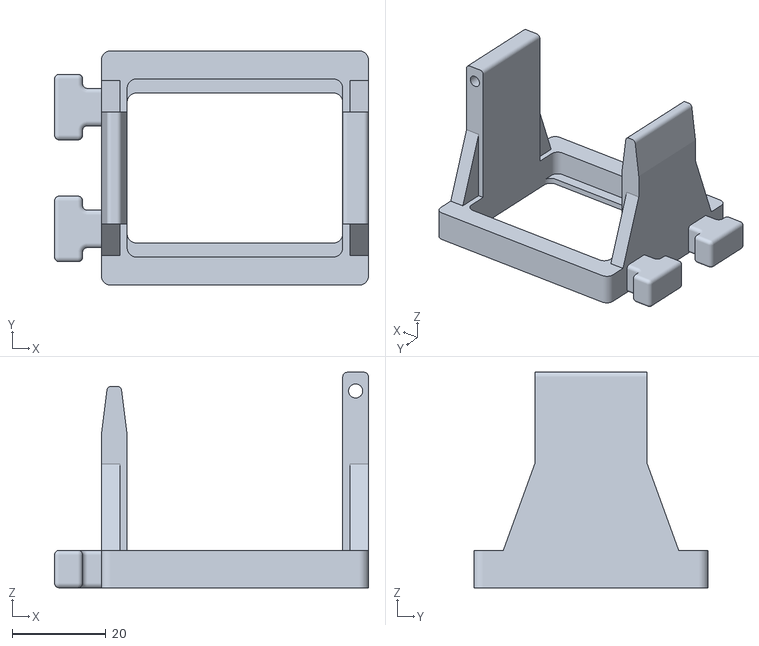
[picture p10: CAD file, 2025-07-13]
cad/Startrampe/PodPad_releasemechanism.stl
67.0 x 50.0 x 46.0

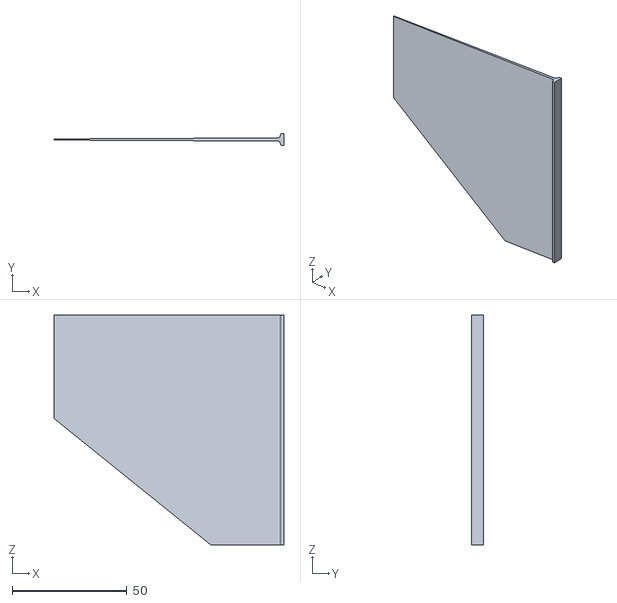
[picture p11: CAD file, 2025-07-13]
cad/Rakete/Rakete - Finne1.stl
100.0 x 5.40 x 100.0

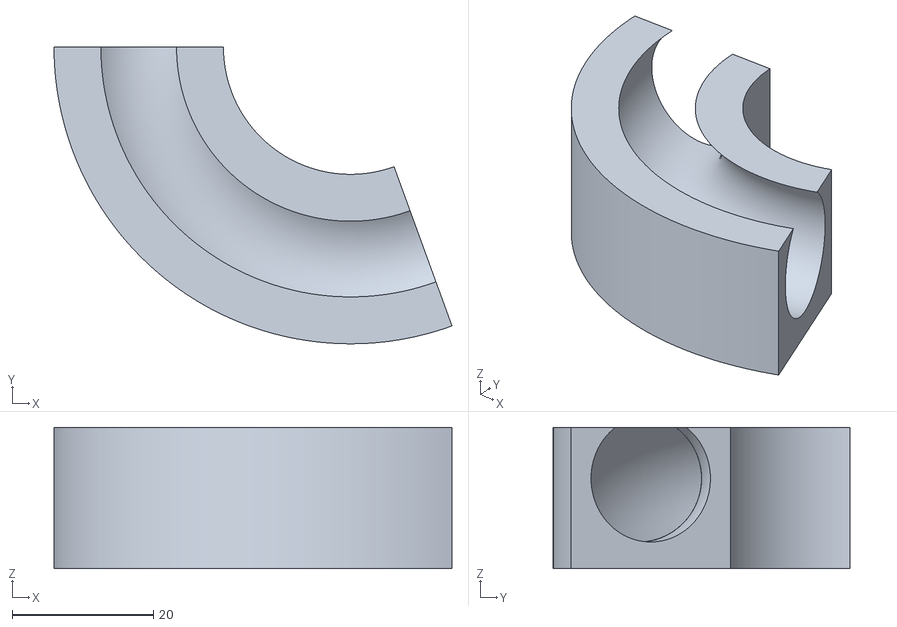
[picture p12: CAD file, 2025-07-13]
cad/Startrampe/PodPad_hosebender.stl
56.4 x 42.0 x 20.0

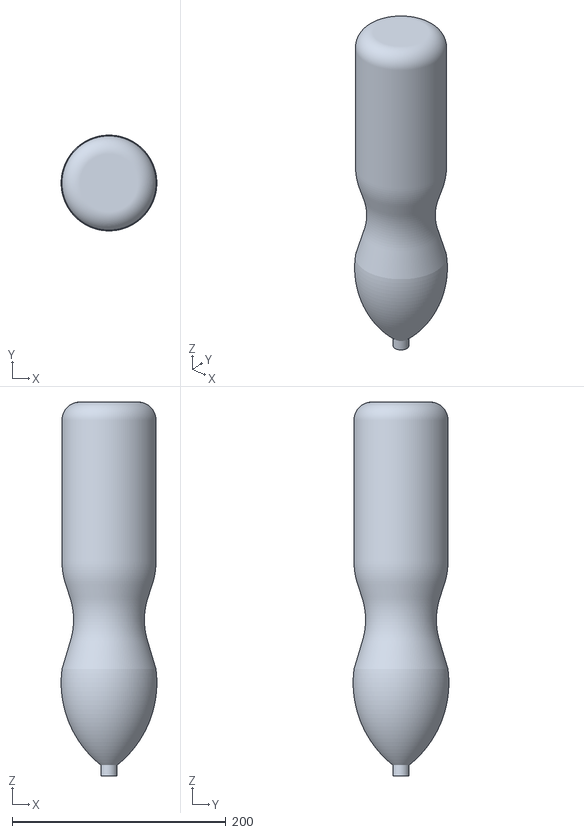
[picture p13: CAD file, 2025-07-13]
cad/Rakete/Rakete - Flasche.stl
89.6 x 89.6 x 350.0

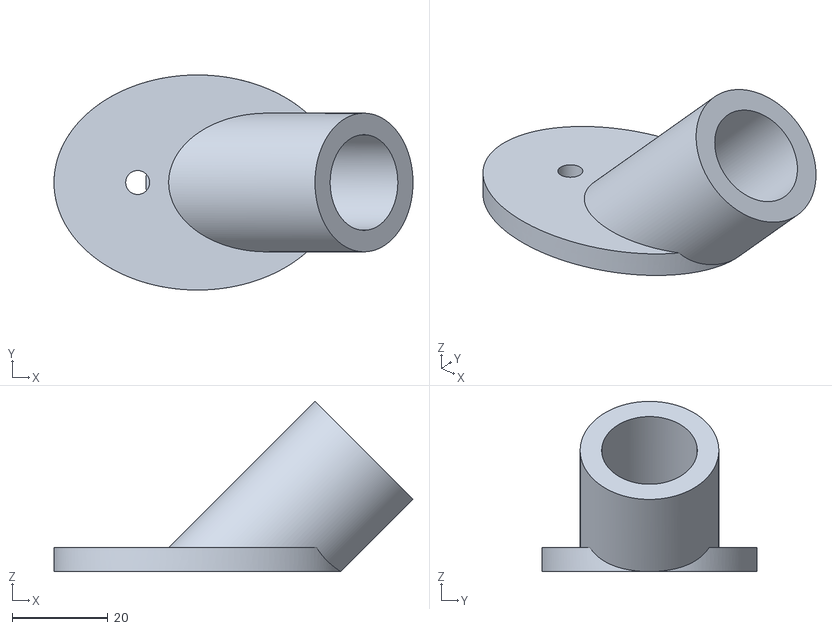
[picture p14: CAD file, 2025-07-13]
cad/Startrampe/PodPad_foot.stl
75.1 x 45.0 x 35.6

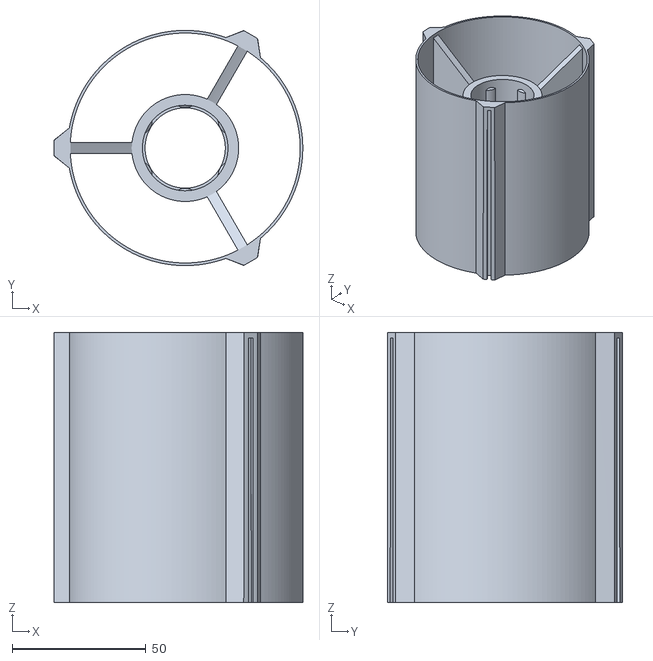
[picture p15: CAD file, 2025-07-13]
cad/Rakete/Rakete - Tailcan.stl
93.0 x 88.0 x 101.0

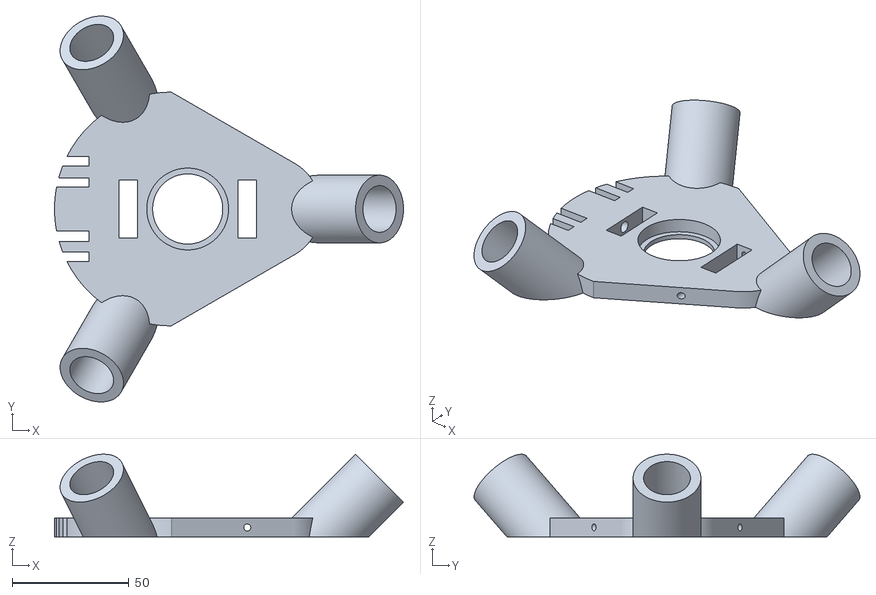
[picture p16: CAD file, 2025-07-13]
cad/Startrampe/PodPad_baseplate.stl
149.4 x 165.1 x 35.4

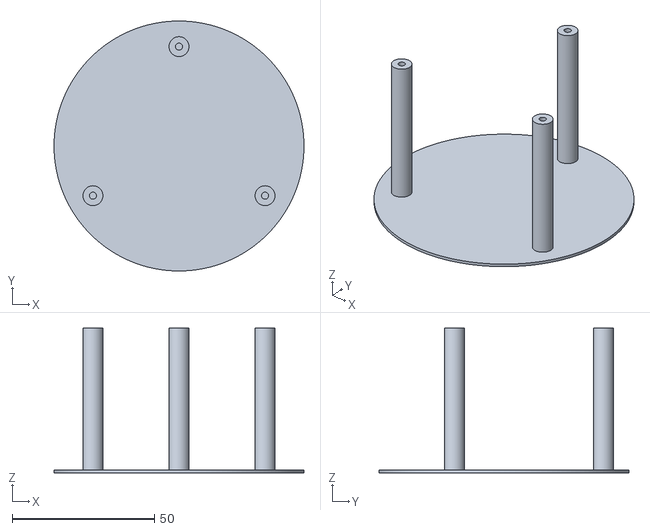
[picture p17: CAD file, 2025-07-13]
cad/Rakete/Rakete - Platzhalter.stl
88.0 x 88.0 x 51.0

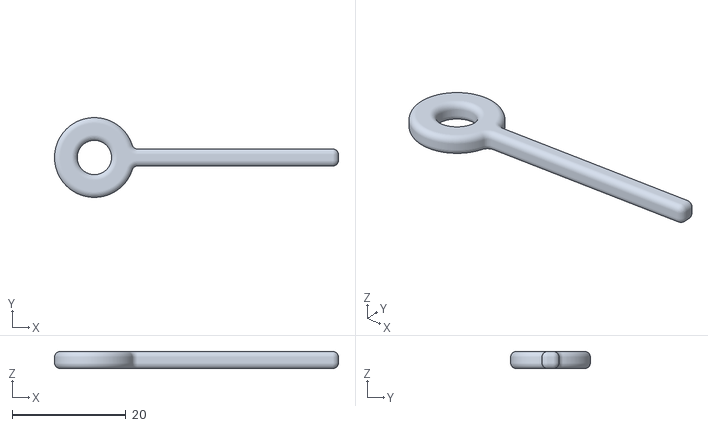
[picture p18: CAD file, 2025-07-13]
cad/Startrampe/PodPad_splint.stl
49.8 x 14.0 x 3.00

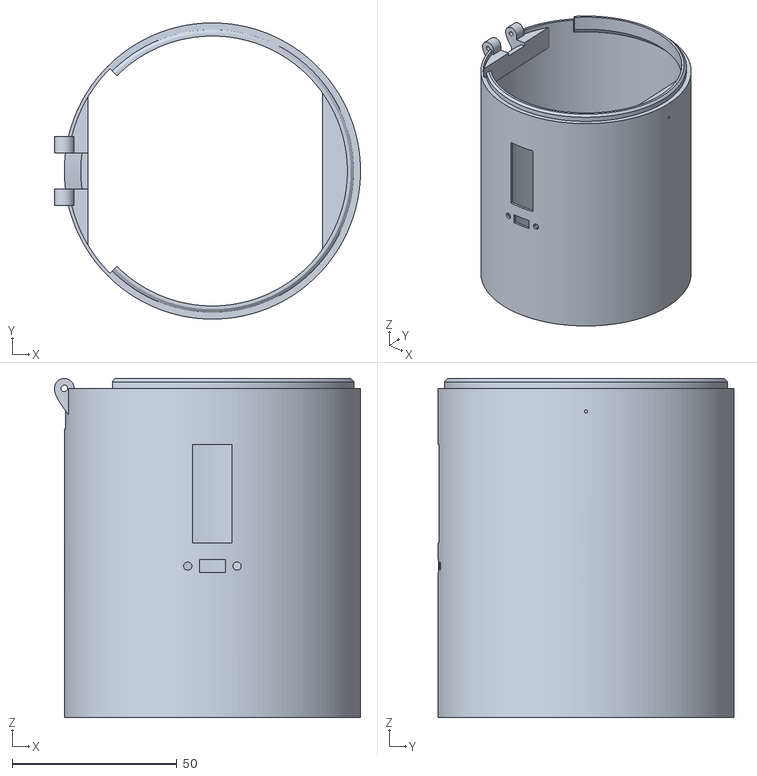
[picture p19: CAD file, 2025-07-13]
cad/Rakete/Rakete - Modul.stl
93.0 x 90.0 x 103.0

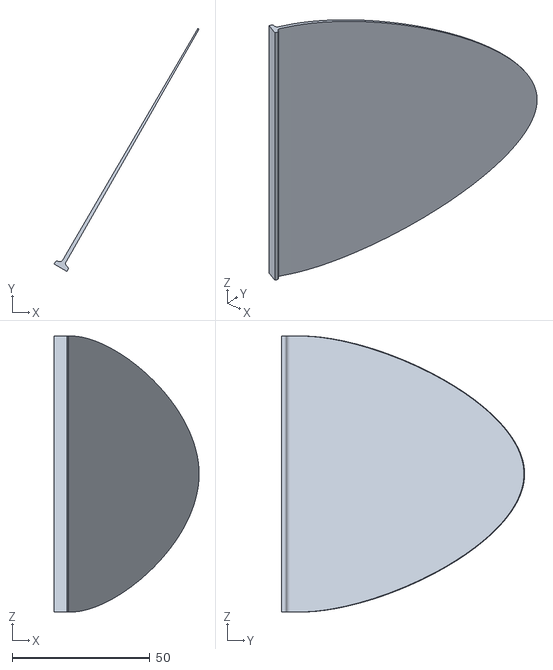
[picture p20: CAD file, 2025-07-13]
cad/Rakete/Rakete - Finne2.stl
52.5 x 88.0 x 100.0

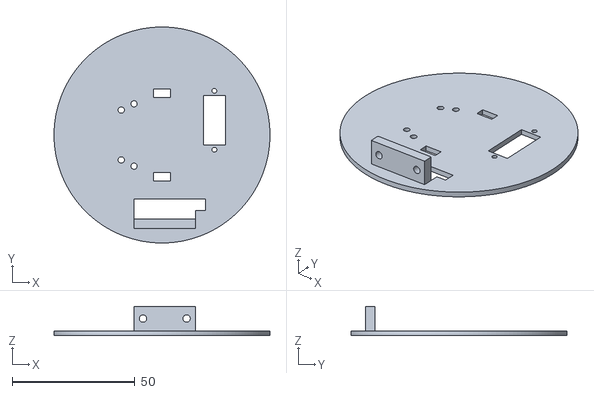
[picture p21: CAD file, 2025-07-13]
cad/Rakete/Rakete - Elektronikplatte.stl
88.0 x 88.0 x 12.0

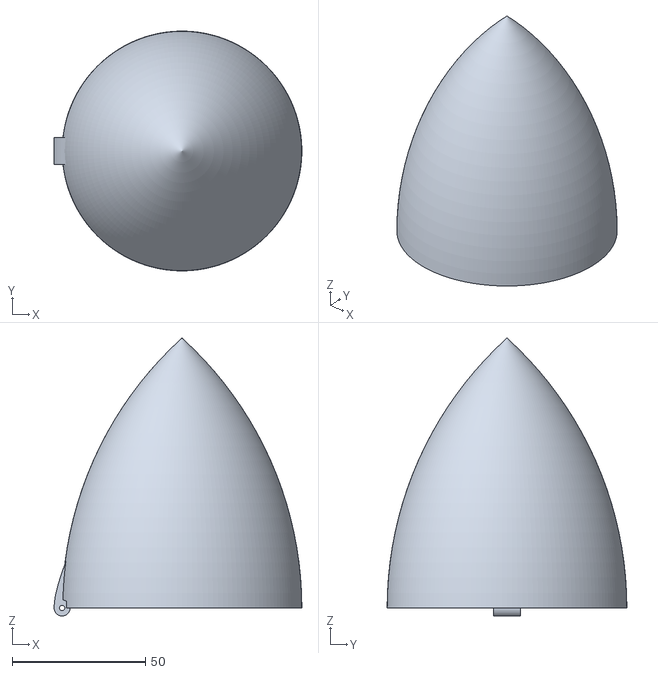
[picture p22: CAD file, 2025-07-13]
cad/Rakete/Rakete - Spitze.stl
93.0 x 90.0 x 104.4

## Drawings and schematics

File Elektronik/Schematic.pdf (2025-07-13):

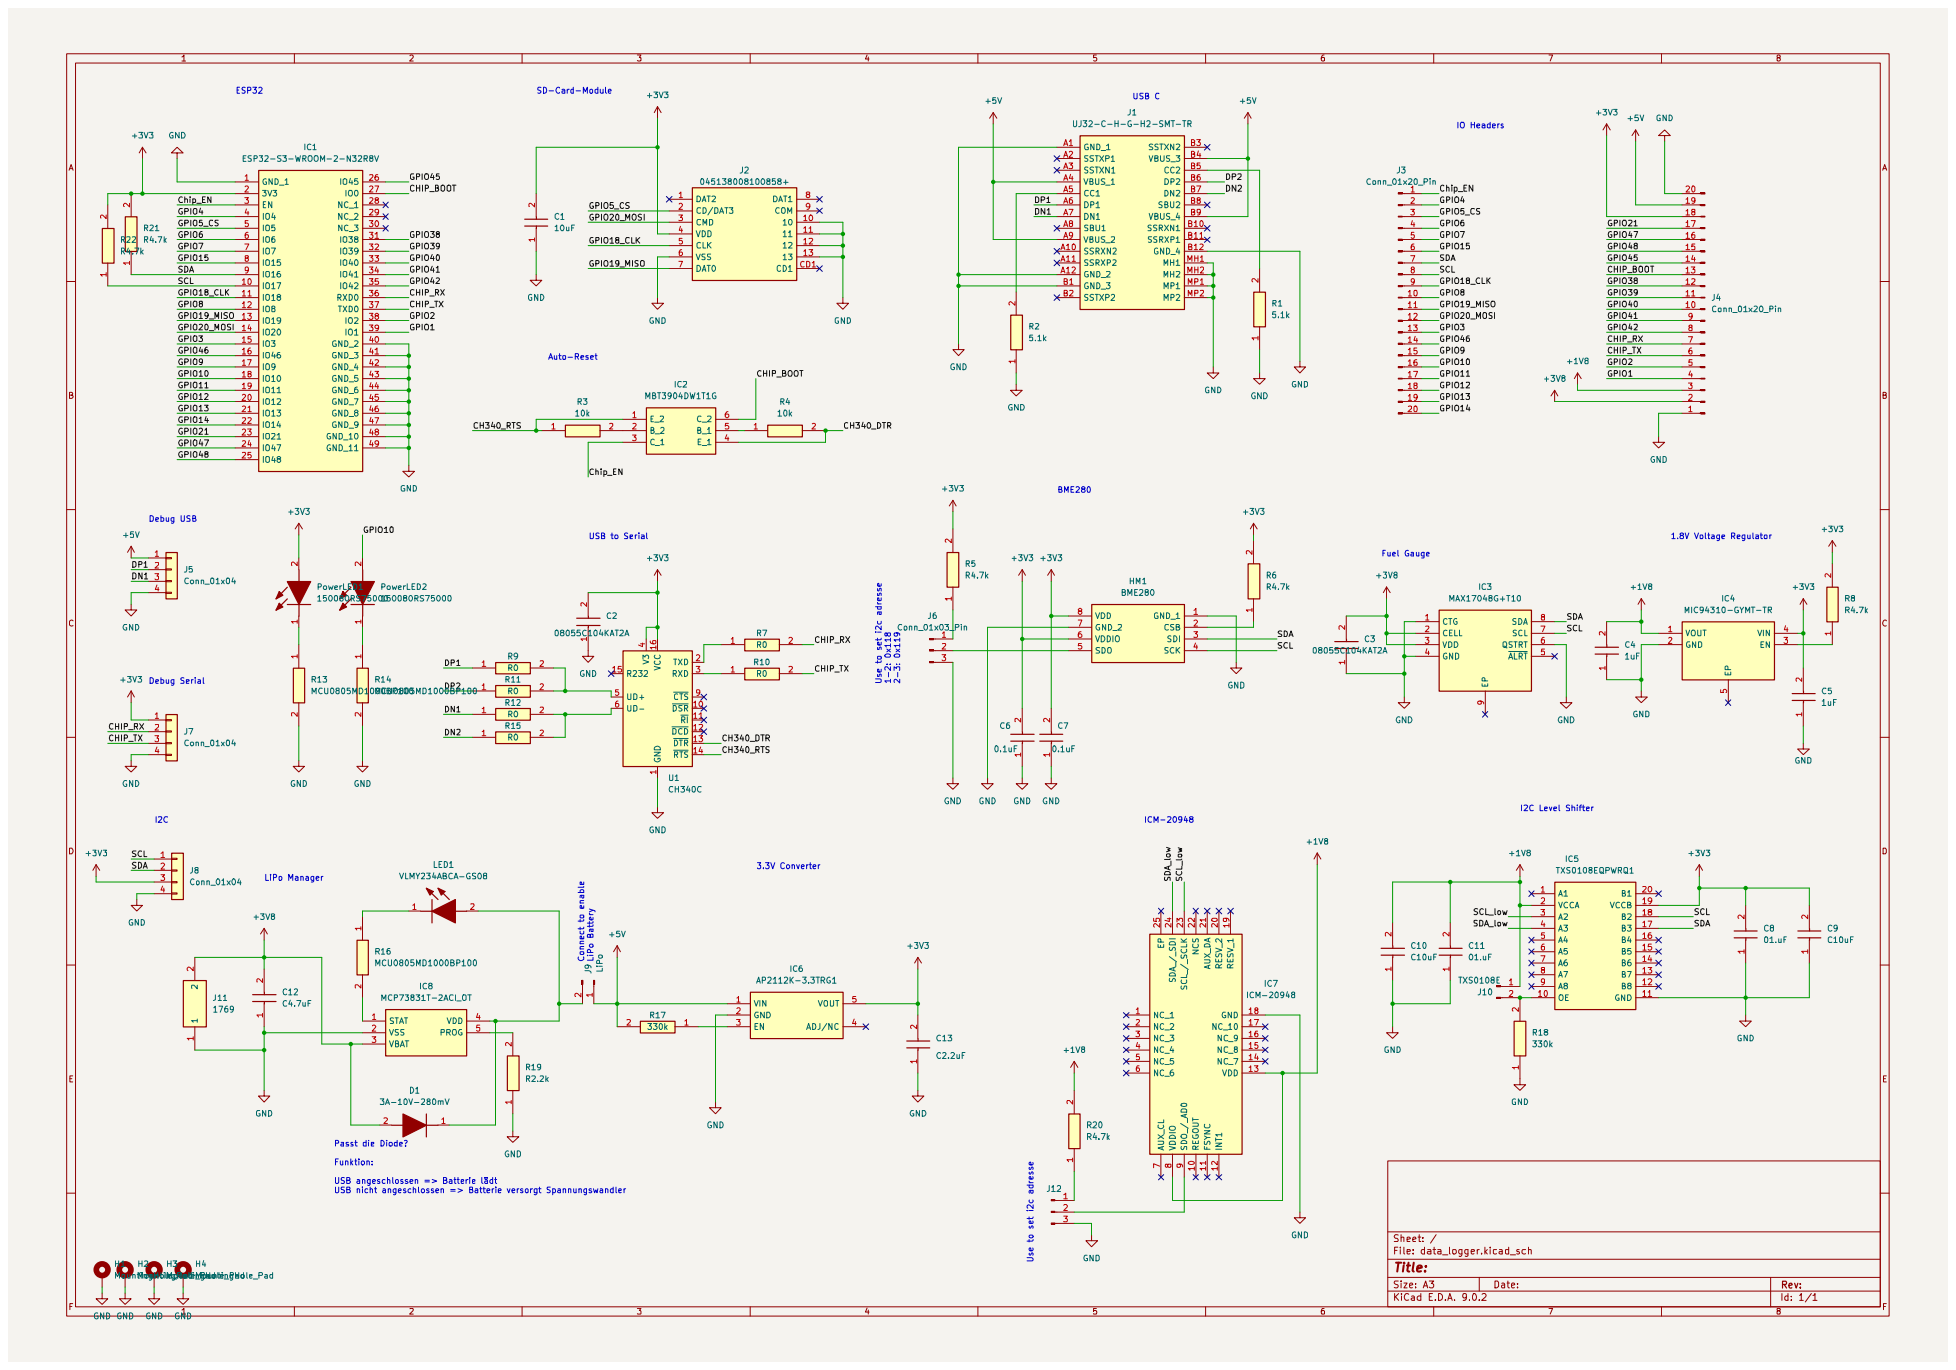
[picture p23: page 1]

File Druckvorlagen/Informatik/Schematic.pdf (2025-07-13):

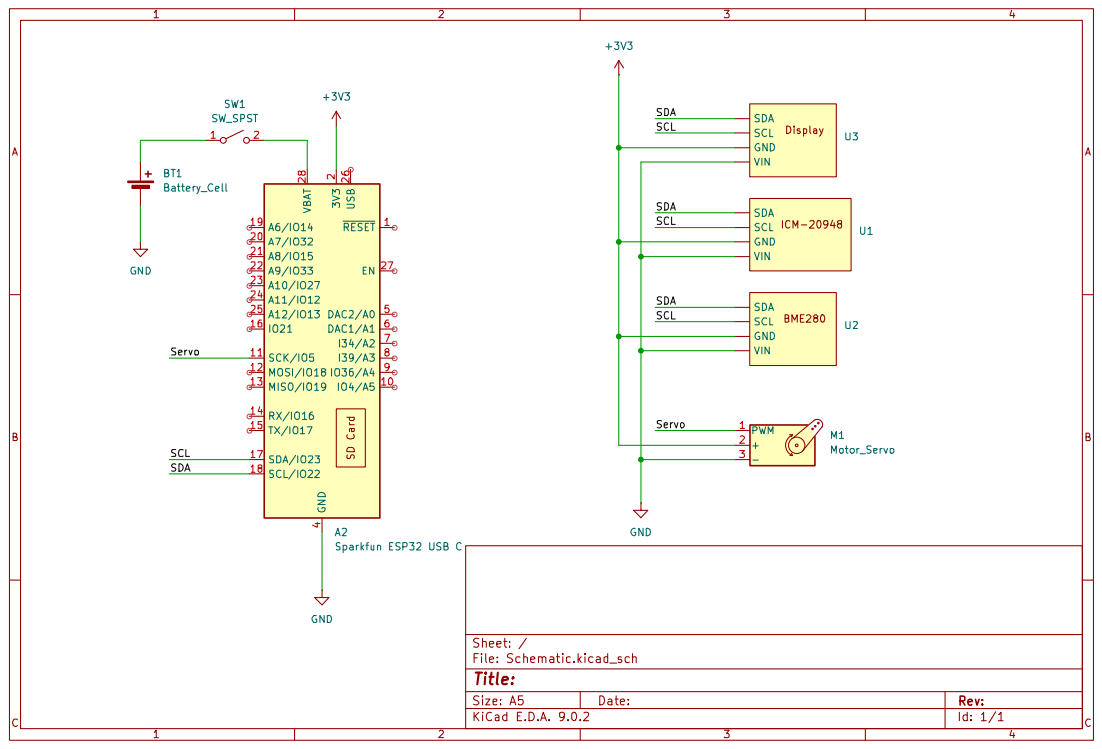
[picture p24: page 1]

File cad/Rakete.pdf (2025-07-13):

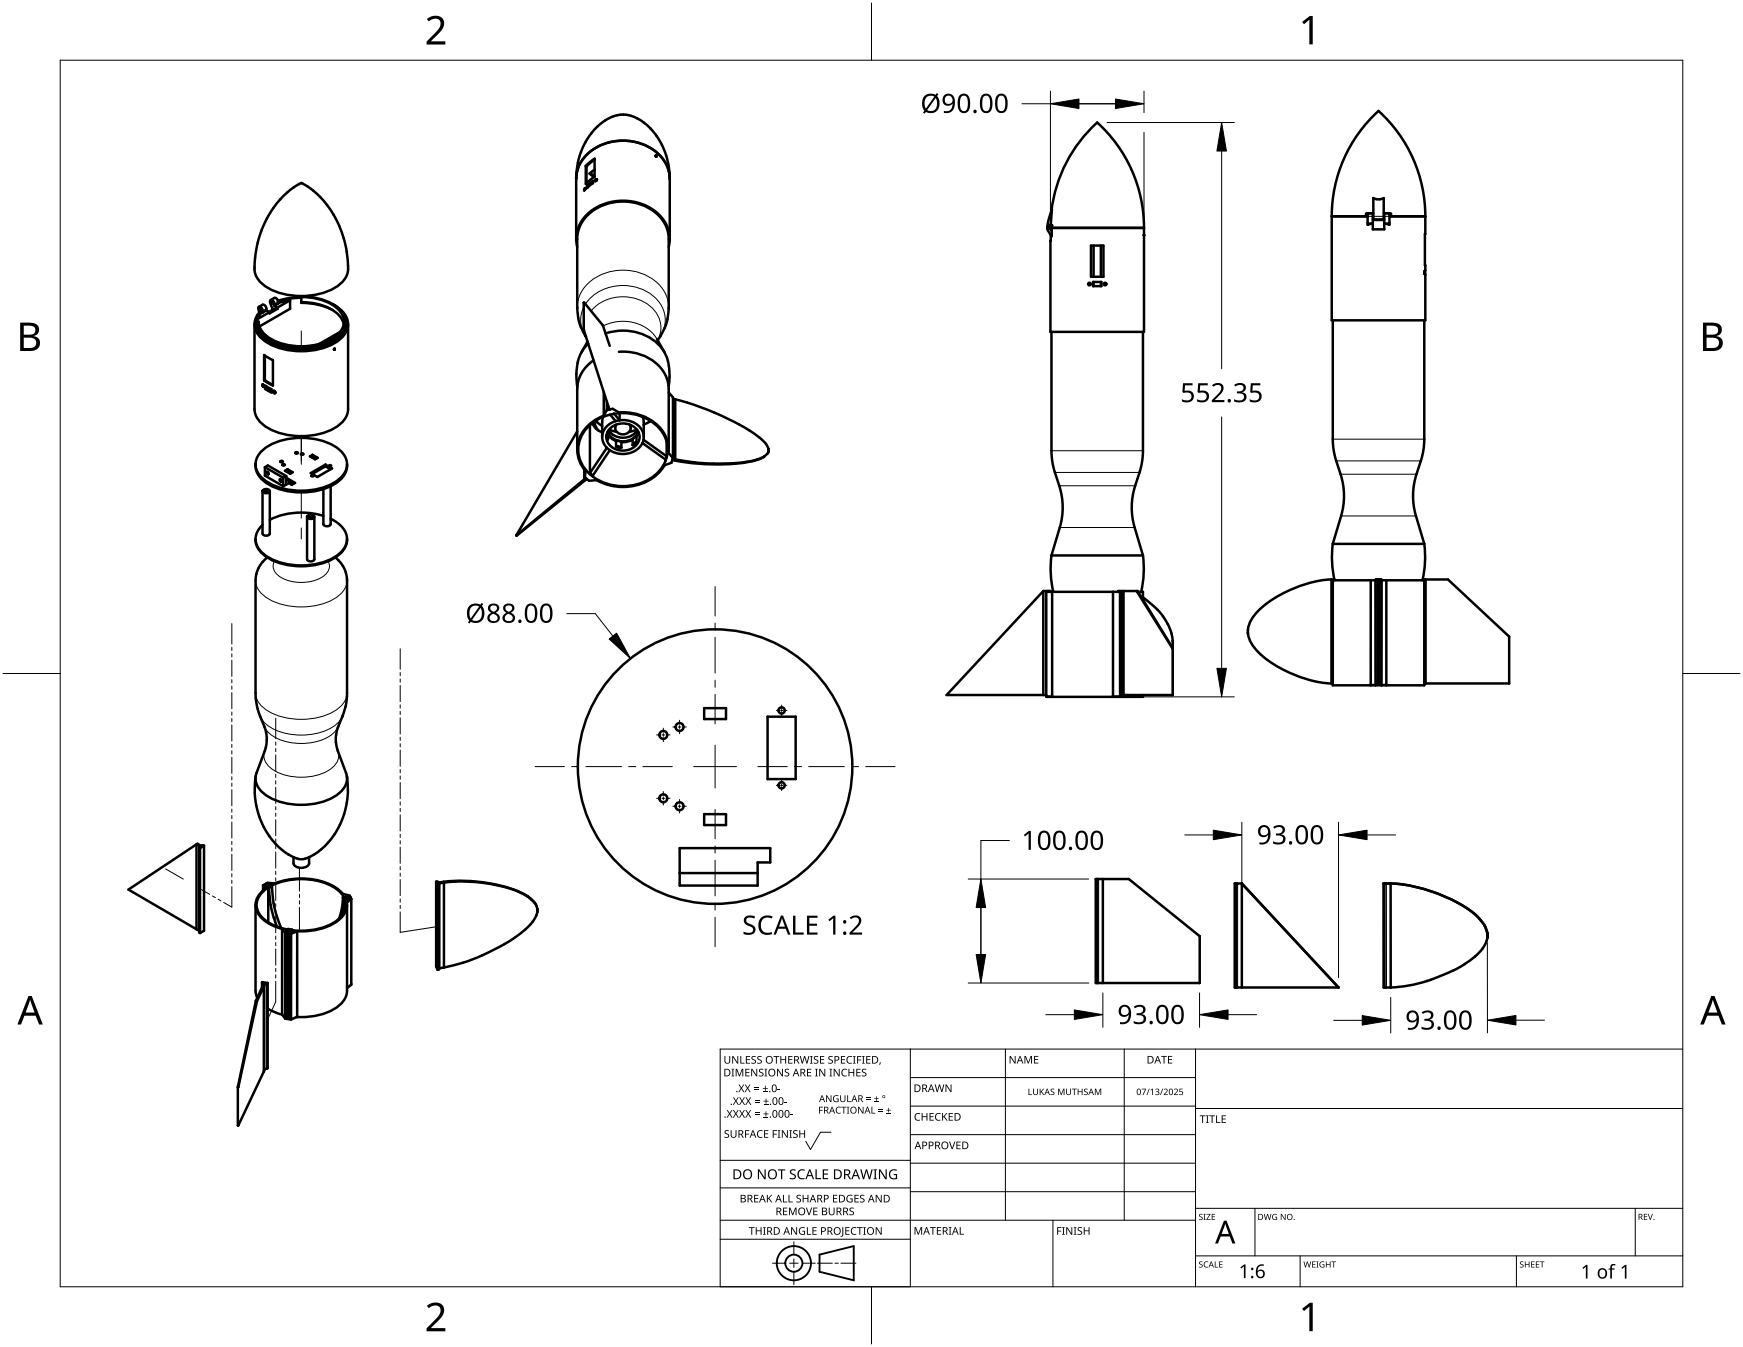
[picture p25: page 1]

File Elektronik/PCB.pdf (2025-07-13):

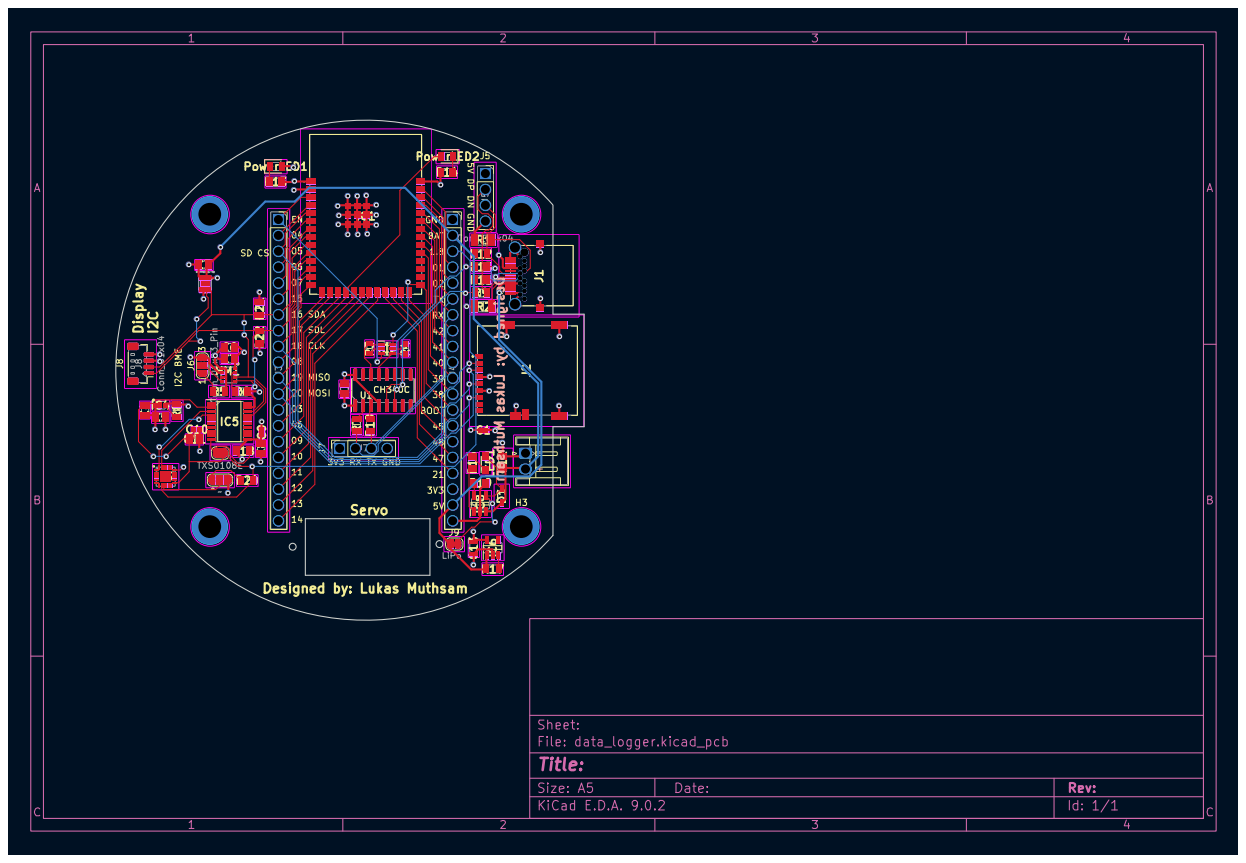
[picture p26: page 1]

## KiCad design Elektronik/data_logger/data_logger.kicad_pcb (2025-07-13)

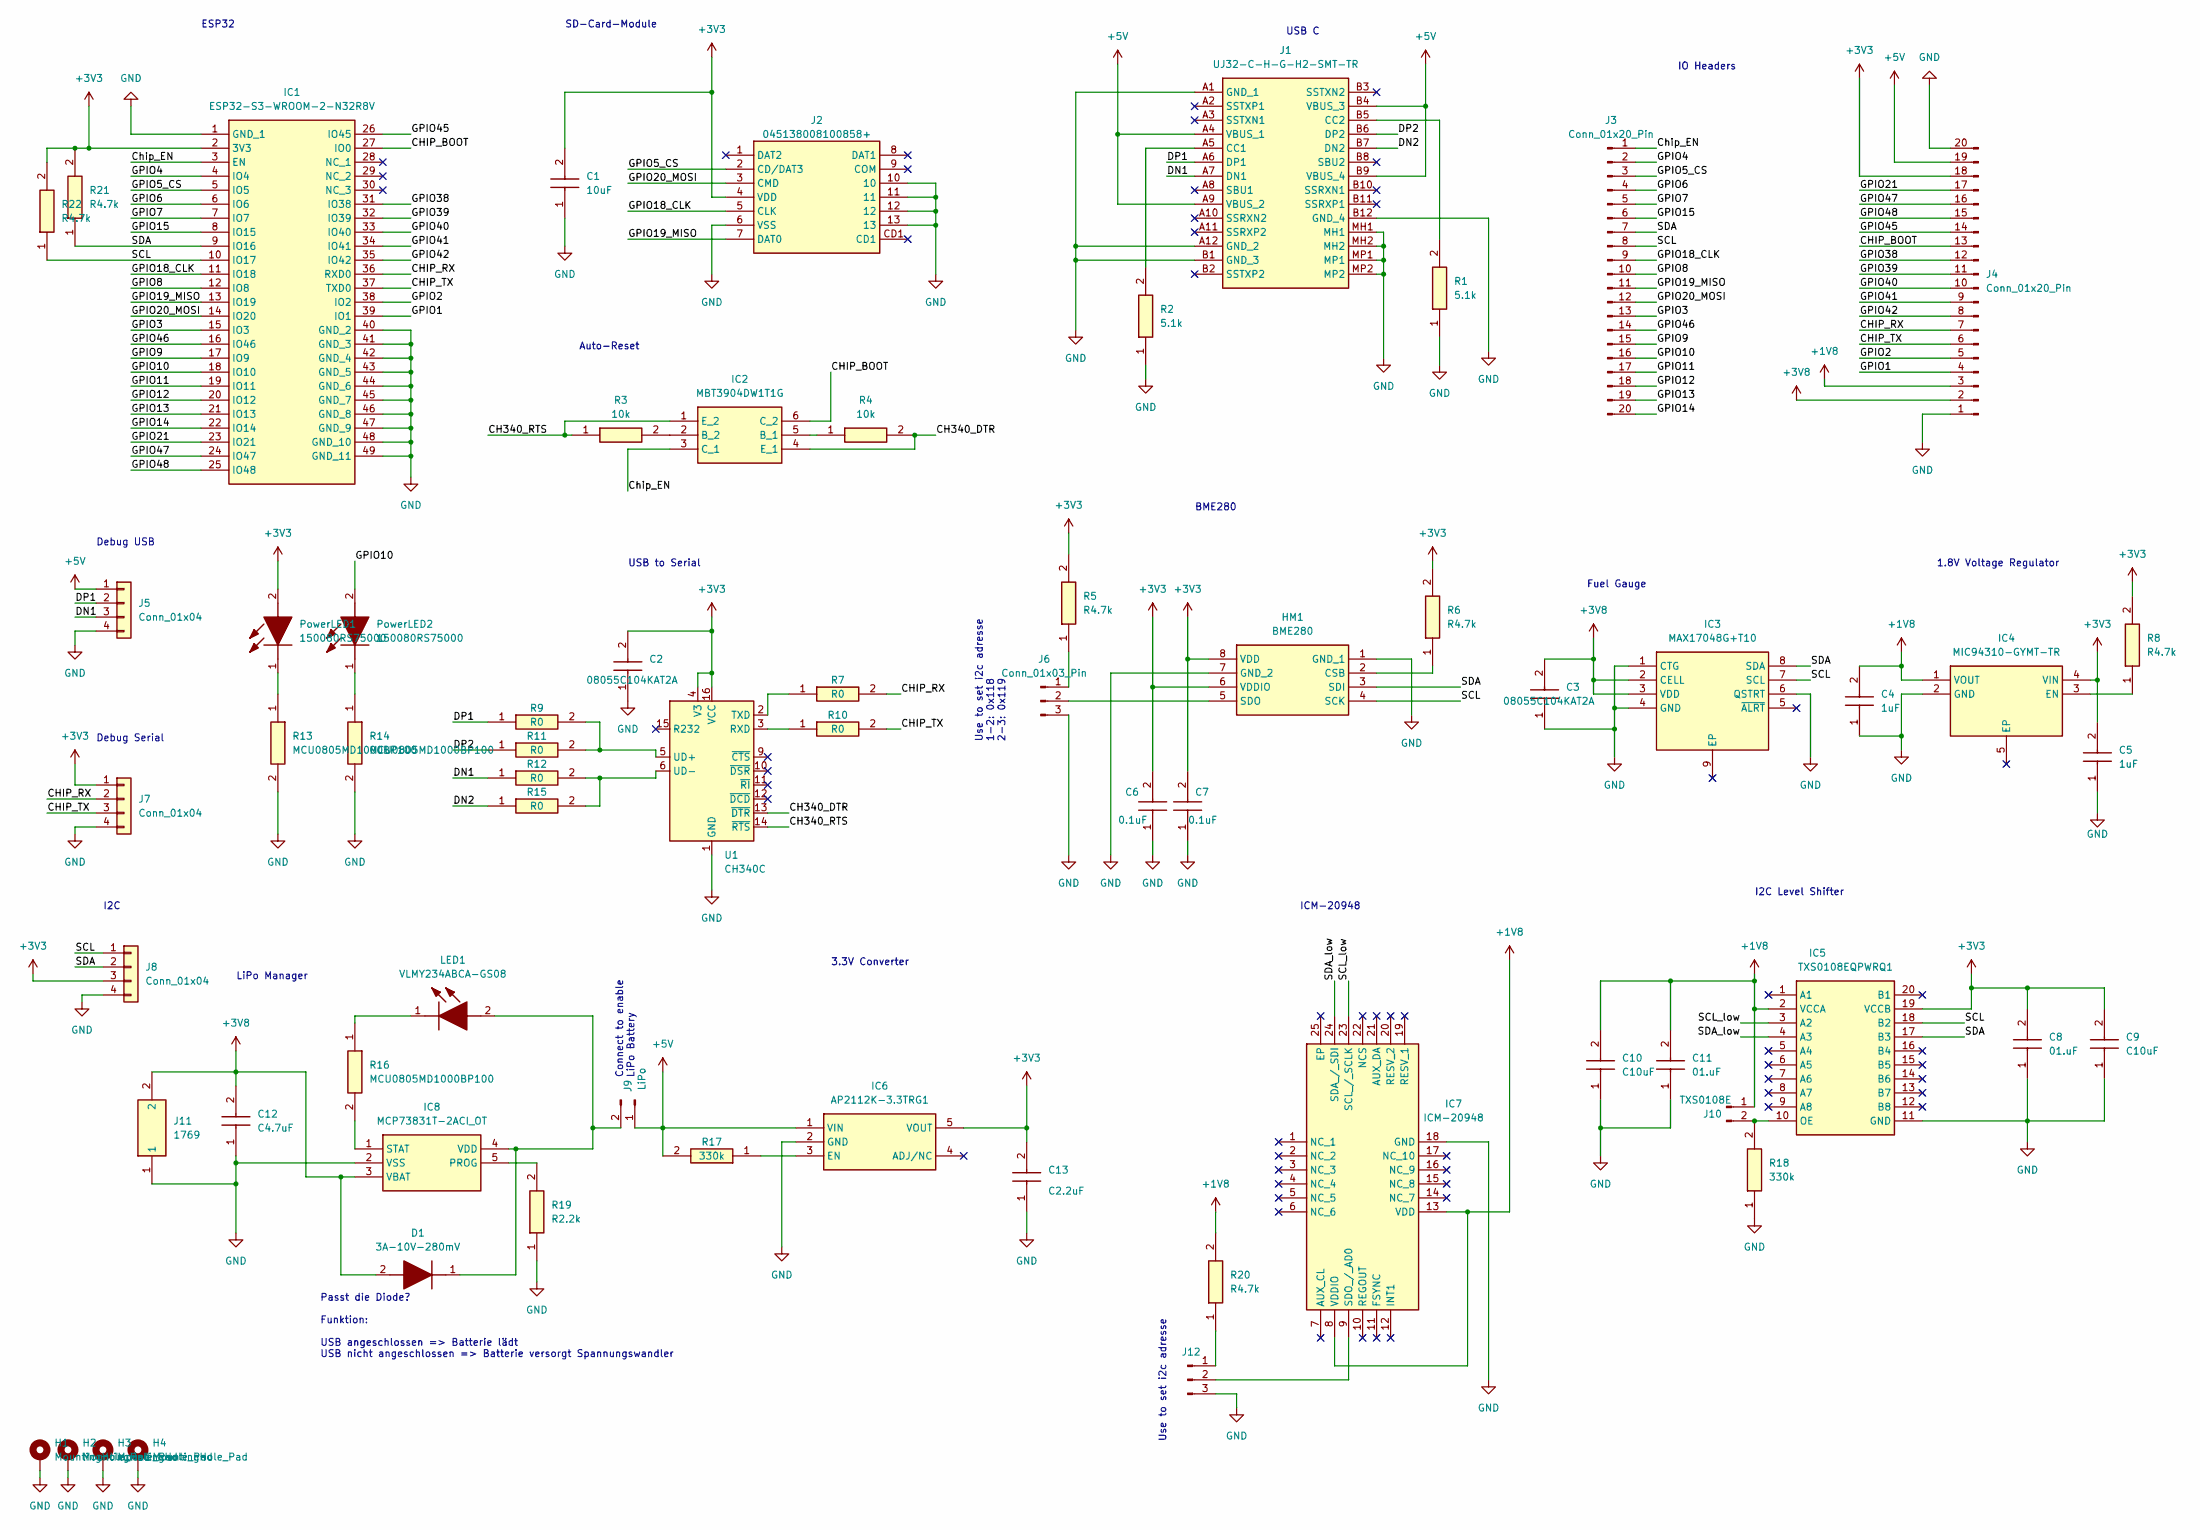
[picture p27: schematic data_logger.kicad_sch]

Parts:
C1: 10uF; CAPC1005X70N; Mouser Part Number 81-GRT155R60J106ME13
C2, C3: 08055C104KAT2A; CAPC2012X94N; Mouser Part Number 581-08055C104K
C4, C5: 1uF; CAPC2012X140N; Mouser Part Number 581-KAF21KR71H105KU
C6, C7: 0.1uF; CAPC2012X94N; Mouser Part Number 581-08055C104K
C8, C11: 01.uF; CAPC2012X94N; Mouser Part Number 581-08055C104K
C9, C10: C10uF; CAPC1005X70N; Mouser Part Number 81-GRT155R60J106ME13
C12: C4.7uF; C0805; Mouser Part Number 80-C0805C475K4RAUTO
C13: C2.2uF; CAPC2012X145N; Mouser Part Number 810-C2012X7R2225K125
D1: 3A-10V-280mV; SOD2513X110N; Mouser Part Number 726-BAT60AE6327HTSA1
H1, H2, H3, H4: MountingHole_Pad; MountingHole_3.2mm_M3_DIN965_Pad_TopBottom
HM1: BME280; Mouser Part Number 262-BME280
IC1: ESP32-S3-WROOM-2-N32R8V; ESP32S3WROOM2N32R8V; Mouser Part Number 356-ESP3S3WRM2N32R8V
IC2: MBT3904DW1T1G; SOT65P210X110-6N; Mouser Part Number 863-MBT3904DW1T1G
IC3: MAX17048G+T10; DFN-8; Mouser Part Number 700-MAX17048G+T10
IC4: MIC94310-GYMT-TR; SON50P155X120X60-5N-D; Mouser Part Number 998-MIC94310-GYMTTR
IC5: TXS0108EQPWRQ1; SOP65P640X120-20N; Mouser Part Number 595-TXS0108EQPWRQ1
IC6: AP2112K-3.3TRG1; SOT95P282X130-5N; Mouser Part Number 621-AP2112K-3.3TRG1
IC7: ICM-20948; QFN40P300X300X105-25N-D; Mouser Part Number 410-ICM-20948
IC8: MCP73831T-2ACI_OT; SOT95P270X145-5N; Mouser Part Number 579-MCP73831T-2ACIOT
J1: UJ32-C-H-G-H2-SMT-TR; UJ32CHGH2SMTTR; Mouser Part Number 179-UJ32CHGH2SMTTR
J2: 045138008100858+; 045138008100858; Mouser Part Number 581-045138008100858+
J3, J4: Conn_01x20_Pin; PinSocket_1x20_P2.54mm_Vertical
J5, J7: Conn_01x04; PinSocket_1x04_P2.54mm_Vertical
J6: Conn_01x03_Pin; SolderJumper-3_P1.3mm_Open_RoundedPad1.0x1.5mm_NumberLabels
J8: Conn_01x04; JST_SH_BM04B-SRSS-TB_1x04-1MP_P1.00mm_Vertical
J9: LiPo; SolderJumper-2_P1.3mm_Bridged_RoundedPad1.0x1.5mm
J10: TXS0108E; SolderJumper-2_P1.3mm_Open_RoundedPad1.0x1.5mm
J11: 1769; JST_EH_S2B-EH_1x02_P2.50mm_Horizontal; Mouser Part Number 485-1769
J12: SolderJumper-3_P1.3mm_Open_RoundedPad1.0x1.5mm
LED1: VLMY234ABCA-GS08; LEDM2214X140N; Mouser Part Number 78-VLMY234ABCA-GS08
PowerLED1, PowerLED2: 150080RS75000; LEDC2012X80N; Mouser Part Number 710-150080RS75000
R1, R2: 5.1k; RESC3116X65N; Mouser Part Number 652-CHP1206AFX-5101L
R3, R4: 10k; RESC1608X55N; Mouser Part Number 594-MCT0603MG1002BP5
R5, R6, R8, R20, R21, R22: R4.7k; RESC2012X50N; Mouser Part Number 71-CRCW08054K70FKEC
R7, R9, R10, R11, R12, R15: R0; RESC2013X84N; Mouser Part Number 71-WSL080500000ZEA9
R13, R14, R16: MCU0805MD1000BP100; RESC2012X62N; Mouser Part Number 594-MCU0805MD1000BP1
R17, R18: 330k; RESC2012X50N; Mouser Part Number 71-RCV0805330KJNEA
R19: R2.2k; RESC2013X65N; Mouser Part Number 71-TNPW08052K20BEEA
U1: CH340C; SOIC-16_3.9x9.9mm_P1.27mm

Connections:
+1V8: C4.2, C10.2, C11.2, IC4.1 (VOUT), IC5.2 (VCCA), IC7.8 (VDDIO), IC7.13 (VDD), J4.3, J10.1, R20.2
+3V3: C1.2, C2.2, C5.2, C6.2, C7.2, C8.2, C9.2, C13.2, HM1.6 (VDDIO), HM1.8 (VDD), IC1.2 (3V3), IC4.4 (VIN), IC5.19 (VCCB), IC6.5 (VOUT), J2.4 (VDD), J4.18, J7.1, J8.3, PowerLED1.2 (A), R5.2, R6.2, R8.2, R21.2, R22.2, U1.4 (V3), U1.16 (VCC)
+3V8: C3.2, C12.2, D1.2 (A), IC3.2 (CELL), IC3.3 (VDD), IC8.3 (VBAT), J4.2, J11.2
+5V: IC6.1 (VIN), J1.A4 (VBUS_1), J1.A9 (VBUS_2), J1.B4 (VBUS_3), J1.B9 (VBUS_4), J4.19, J5.1, J9.1, R17.2
/CH340_DTR: IC2.4 (E_1), R4.2, U1.13 (~DTR)
/CH340_RTS: IC2.1 (E_2), R3.1, U1.14 (~RTS)
/CHIP_BOOT: IC1.27 (IO0), IC2.6 (C_2), J4.13
/CHIP_RX: IC1.36 (RXD0), J4.7, J7.2, R7.2
/CHIP_TX: IC1.37 (TXD0), J4.6, J7.3, R10.2
/Chip_EN: IC1.3 (EN), IC2.3 (C_1), J3.1
/DN1: J1.A7 (DN1), J5.3, R12.1
/DN2: J1.B7 (DN2), R15.1
/DP1: J1.A6 (DP1), J5.2, R9.1
/DP2: J1.B6 (DP2), R11.1
/GPIO1: IC1.39 (IO1), J4.4
/GPIO2: IC1.38 (IO2), J4.5
/GPIO3: IC1.15 (IO3), J3.13
/GPIO4: IC1.4 (IO4), J3.2
/GPIO5_CS: IC1.5 (IO5), J2.2 (CD/DAT3), J3.3
/GPIO6: IC1.6 (IO6), J3.4
/GPIO7: IC1.7 (IO7), J3.5
/GPIO8: IC1.12 (IO8), J3.10
/GPIO9: IC1.17 (IO9), J3.15
/GPIO10: IC1.18 (IO10), J3.16, PowerLED2.2 (A)
/GPIO11: IC1.19 (IO11), J3.17
/GPIO12: IC1.20 (IO12), J3.18
/GPIO13: IC1.21 (IO13), J3.19
/GPIO14: IC1.22 (IO14), J3.20
/GPIO15: IC1.8 (IO15), J3.6
/GPIO18_CLK: IC1.11 (IO18), J2.5 (CLK), J3.9
/GPIO19_MISO: IC1.13 (IO19), J2.7 (DAT0), J3.11
/GPIO20_MOSI: IC1.14 (IO20), J2.3 (CMD), J3.12
/GPIO21: IC1.23 (IO21), J4.17
/GPIO38: IC1.31 (IO38), J4.12
/GPIO39: IC1.32 (IO39), J4.11
/GPIO40: IC1.33 (IO40), J4.10
/GPIO41: IC1.34 (IO41), J4.9
/GPIO42: IC1.35 (IO42), J4.8
/GPIO45: IC1.26 (IO45), J4.14
/GPIO46: IC1.16 (IO46), J3.14
/GPIO47: IC1.24 (IO47), J4.16
/GPIO48: IC1.25 (IO48), J4.15
/SCL: HM1.4 (SCK), IC1.10 (IO17), IC3.7 (SCL), IC5.18 (B2), J3.8, J8.1, R22.1
/SCL_low: IC5.3 (A2), IC7.23 (SCL_/_SCLK)
/SDA: HM1.3 (SDI), IC1.9 (IO16), IC3.8 (SDA), IC5.17 (B3), J3.7, J8.2, R21.1
/SDA_low: IC5.4 (A3), IC7.24 (SDA_/_SDI)
GND: C1.1, C2.1, C3.1, C4.1, C5.1, C6.1, C7.1, C8.1, C9.1, C10.1, C11.1, C12.1, C13.1, H1.1, H2.1, H3.1, H4.1, HM1.1 (GND_1), HM1.7 (GND_2), IC1.1 (GND_1), IC1.40 (GND_2), IC1.41 (GND_3), IC1.42 (GND_4), IC1.43 (GND_5), IC1.44 (GND_6), IC1.45 (GND_7), IC1.46 (GND_8), IC1.47 (GND_9), IC1.48 (GND_10), IC1.49 (GND_11), IC3.1 (CTG), IC3.4 (GND), IC3.6 (QSTRT), IC4.2 (GND), IC5.11 (GND), IC6.2 (GND), IC7.18 (GND), IC8.2 (VSS), J1.A1 (GND_1), J1.A12 (GND_2), J1.B1 (GND_3), J1.B12 (GND_4), J1.MH1, J1.MH2, J1.MP1, J1.MP2, J2.6 (VSS), J2.10, J2.11, J2.12, J2.13, J4.1, J4.20, J5.4, J6.3, J7.4, J8.4, J11.1, J12.3, R1.1, R2.1, R13.2, R14.2, R18.1, R19.1, U1.1 (GND)
unnamed: D1.1 (K), IC8.4 (VDD), J9.2, LED1.2 (A)
unnamed: HM1.2 (CSB), R6.1
unnamed: HM1.5 (SDO), J6.2
unnamed: IC2.5 (B_1), R4.1
unnamed: IC2.2 (B_2), R3.2
unnamed: IC4.3 (EN), R8.1
unnamed: IC5.10 (OE), J10.2, R18.2
unnamed: IC6.3 (EN), R17.1
unnamed: IC7.9 (SDO_/_AD0), J12.2
unnamed: IC8.5 (PROG), R19.2
unnamed: IC8.1 (STAT), R16.2
unnamed: J1.A5 (CC1), R2.2
unnamed: J1.B5 (CC2), R1.2
unnamed: J6.1, R5.1
unnamed: J12.1, R20.1
unnamed: LED1.1 (K), R16.1
unnamed: PowerLED1.1 (K), R13.1
unnamed: PowerLED2.1 (K), R14.1
unnamed: R10.1, U1.3 (RXD)
unnamed: R7.1, U1.2 (TXD)
unnamed: R9.2, R11.2, U1.5 (UD+)
unnamed: R12.2, R15.2, U1.6 (UD-)

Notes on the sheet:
I2C Level Shifter
Use to set i2c adresse
1.8V Voltage Regulator
Use to set i2c adresse 1-2: 0x118 2-3: 0x119
I2C
Debug USB
ICM-20948
Fuel Gauge
IO Headers
Connect to enable LiPo Battery
USB C
Passt die Diode? Funktion: USB angeschlossen => Batterie lädt USB nicht angeschlossen => Batterie versorgt Spannungswandler
3.3V Converter
USB to Serial
BME280
LiPo Manager
ESP32
Debug Serial
SD-Card-Module
Auto-Reset

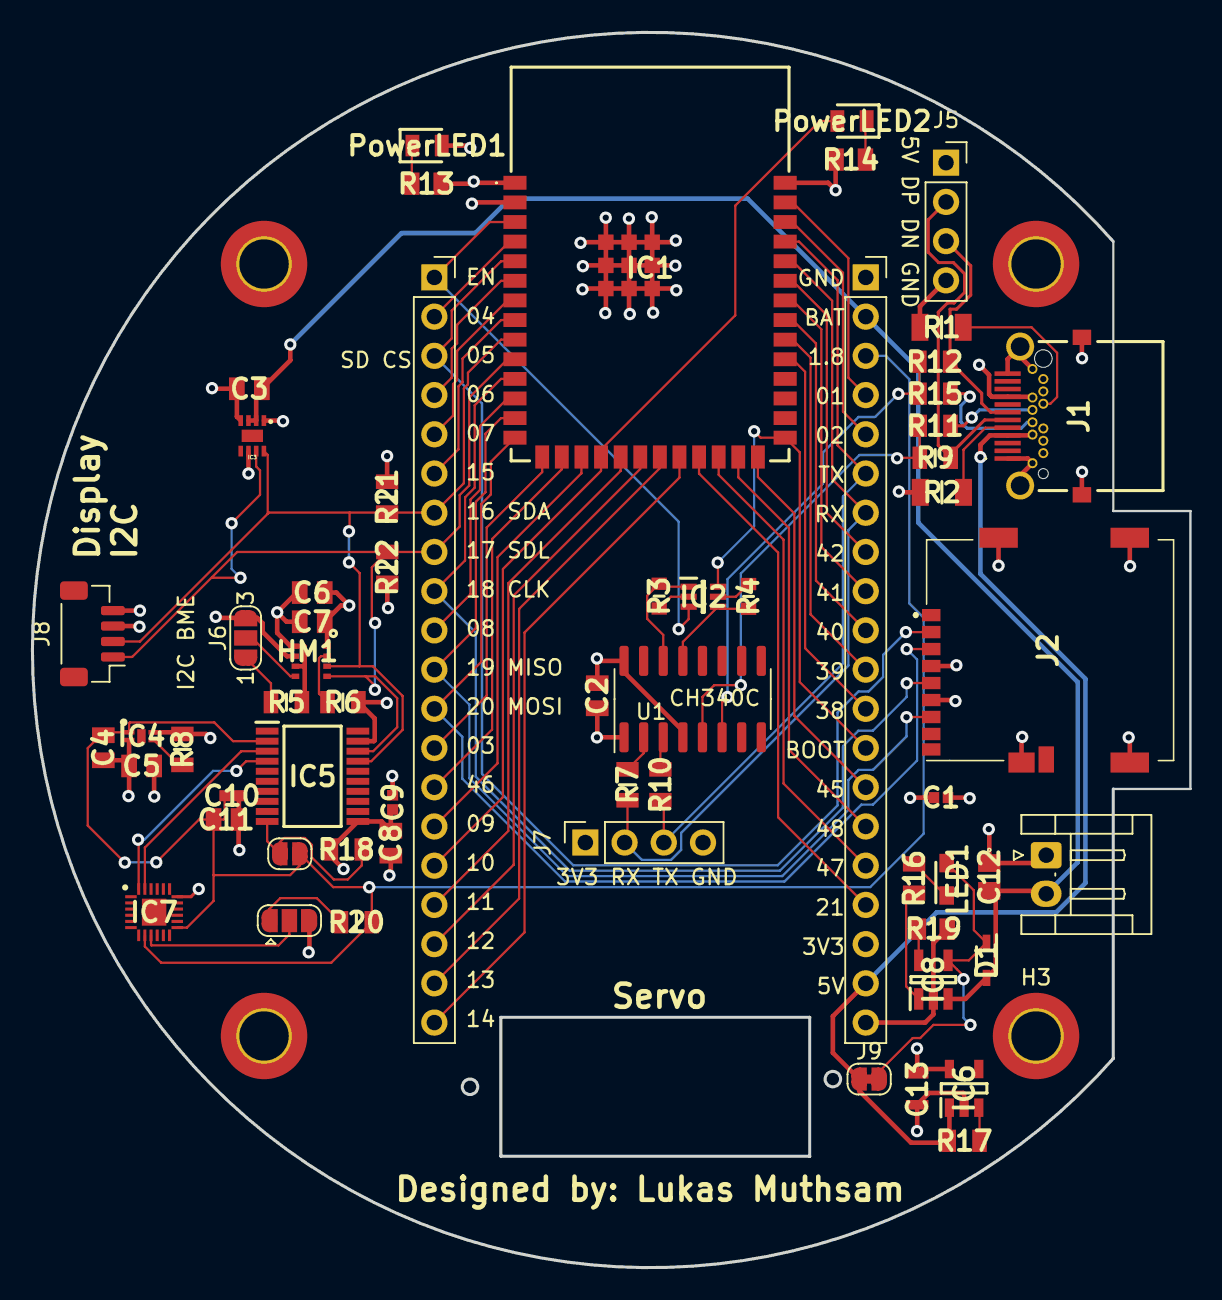
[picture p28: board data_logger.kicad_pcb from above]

Board: 4 copper layers, 75.0 x 80.0 mm, 65 parts (0 on the bottom side), 69 nets.

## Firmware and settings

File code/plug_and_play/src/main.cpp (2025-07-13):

// #include "SparkFun_BNO08x_Arduino_Library.h"
// #include <Adafruit_BNO08x.h>

#include "Rakete_BME280.h"
#include "Rakete_Display.h"
#include "Rakete_ICM20948.h"
#include "Rakete_MAX17048.h"
#include "Rakete_Servo.h"
#include "Rakete_Webserver.h"

#include <Arduino.h>
#include <AsyncEventSource.h>
#include <AsyncTCP.h>
#include <ESPAsyncWebServer.h>
#include <FS.h>
#include <SD.h>
#include <SPI.h>

#include <WiFi.h>
#include <Wire.h>

// // WLAN
// #define SSID "UniFi"
// #define PASSPHRASE "lassmichbitterein"

// WLAN
#define SSID "THAir"
#define PASSPHRASE "RoboterUSG1!"

// WLAN AP
#define SSID_AP "ESP32"
#define PASSPHRASE_AP "12345678"

// Webserver

// Pinbelegung SPI
#define MISO 19 // Data In
#define MOSI 23 // Data Out
#define SCK 18  // Clock

#define SD_CS 5 // Chip Select (CS) für die SD-Karte

File csvFile;

// Pinbelegung I2C
#define SDA 21 // Data Line
#define SCL 22 // Clock Line

Rakete_ICM20948 icm;
bool icm_active = false;

Rakete_BME280 bme;
bool bme_active = false;
float max_altitude = 0.0f;
float min_altitude = 3000.0f;

Rakete_Servo servo(15);

Rakete_MAX17048 lipo;
bool lipo_active = false;

Rakete_Display display(32, 128);
bool oled_active = false;

Rakete_Webserver webserver;

bool parachute_deployed = false;
bool parachute_deploying = false;
int last_parachute = 0;

#define PUBLISH_INTERVAL                                                       \
  100 // Zeitintervall für die Veröffentlichung von Daten in Millisekunden
uint32_t nextMicros;

struct LogEntry {
  uint32_t timestamp;                    // Zeitstempel der Aufnahme
  float temp, hum, pres, altitude;       // BME280 Messwerte
  float yaw, pitch, roll;                // BNO08x Euler-Winkel in Grad
  float linAccelX, linAccelY, linAccelZ; // BNO08x lineare Beschleunigung
  float accelX, accelY, accelZ;          // BNO08x Beschleunigung
  float soc, voltage;                    // MAX17048 Ladezustand und Spannung
};

void mountSD();
void connectWifi();

void startRecording();

void setup() {
  Serial.begin(115200);

  delay(100);
  Serial.println("Start");

  // ---- I2C initialisieren ----
  Wire.begin(SDA, SCL);
  Serial.println("I2C initialized");

  // ---- SPI initialisieren ----
  SPI.begin(SCK, MISO, MOSI, SD_CS);
  Serial.println("SPI initialized");

  bme_active = bme.init();

  icm_active = icm.init();

  lipo_active = lipo.init();

  oled_active = display.init();

  display.show("Bat: \n" + String(lipo.getSOC()) + "%");

  delay(500);

  servo.init();

  connectWifi();

  mountSD();

  webserver.init();

  startRecording();

  display.show("Launch -> ");
}

void saveBattery() {
  String payload = "{";
  payload += "\"soc\":" + String(lipo.getSOC(), 1) + ",";
  payload += "\"voltage\":" + String(lipo.getVoltage(), 3);
  payload += "}";

  File jsonFile = SD.open("/battery.json", FILE_WRITE);
  if (jsonFile) {
    jsonFile.print(payload);
    jsonFile.close();
  }

  display.show("Launch -> ");
}

void startRecording() {
  Serial.println("Aufnahme gestartet");

  uint16_t maxIndex = 0;
  File root = SD.open("/");
  while (true) {
    File entry = root.openNextFile();
    if (!entry)
      break;

    if (!entry.isDirectory()) {
      const char *fullName = entry.name();
      const char *fn = fullName[0] == '/' ? fullName + 1 : fullName;
      if (strncmp(fn, "log_", 4) == 0 && strlen(fn) == 12 && fn[8] == '.' &&
          tolower(fn[9]) == 'c' && tolower(fn[10]) == 's' &&
          tolower(fn[11]) == 'v') {
        char num[5] = {fn[4], fn[5], fn[6], fn[7], 0};
        uint16_t idx = atoi(num);
        if (idx > maxIndex)
          maxIndex = idx;
      }
    }
    entry.close();
  }
  root.close();

  uint16_t newIndex = maxIndex + 1;
  char filename[16];
  sprintf(filename, "/log_%04d.csv", newIndex);
  Serial.print("Erstelle neue Datei: ");
  Serial.println(filename);

  csvFile = SD.open(filename, FILE_WRITE);
  if (!csvFile) {
    Serial.println("Fehler beim Erstellen der CSV-Datei!");
    return;
  }

  csvFile.println("time_us,temp_C,hum_pct,press_hPa,altitude_m,accelX,"
                  "accelY,accelZ,voltage_V");
  csvFile.flush();
}

void connectWifi() {
  // Initialize WiFi
  WiFi.begin(SSID, PASSPHRASE);
  Serial.print("\nConnecting to WiFi...");

  for (int i = 0; i < 2; i++) {
    delay(1000);
    Serial.print(".");
  }

  if (WiFi.status() != WL_CONNECTED) {

    Serial.println("FEHLER: WiFi nicht verbunden");

    WiFi.softAP(SSID_AP, PASSPHRASE_AP);
    Serial.println("Own AP started");

    return;

  } else {

    Serial.println("\nConnected to WiFi");
    Serial.print("IP Address: ");
    Serial.println(WiFi.localIP());
  }
}

void mountSD() {
  Serial.print("SD-Karte initialisieren...");
  if (!SD.begin(SD_CS, SPI, 4000000)) {
    Serial.println(" FEHLER!");
    delay(1000);
  } else {
    Serial.println(" OK");
  }

  Serial.print("SD-Karte Typ: ");
  switch (SD.cardType()) {
  case CARD_NONE:
    Serial.println(" Keine Karte");
    break;
  case CARD_MMC:
    Serial.println(" MMC");
    break;
  case CARD_SD:
    Serial.println(" SDSC");
    break;
  case CARD_SDHC:
    Serial.println(" SDHC");
    break;
  case CARD_UNKNOWN:
    Serial.println(" unbekannt");
    break;
  }
  Serial.print("SD-Karte Größe: ");
  uint64_t cardSize = SD.cardSize() / (1024 * 1024); // Size in MB
  Serial.print(cardSize);
  Serial.println(" MB");

  Serial.print("SD-Karte verfügbarer Speicher: ");
  uint64_t freeSpace = SD.totalBytes() - SD.usedBytes();
  freeSpace /= (1024 * 1024); // Convert to MB
  Serial.print(freeSpace);
  Serial.println(" MB");

  webserver.saveJsonListing("/list.json");
}

void record() {
  LogEntry entry;
  entry.timestamp = micros();

  // BME280
  if (bme_active) {
    entry.temp = bme.getTemperatur();
    entry.hum = bme.getHumidity();
    entry.pres = bme.getPressure() / 100.0; // hPa
    entry.altitude = bme.getAltitude();
  } else {
    entry.temp = entry.hum = entry.pres = 0.0f;
  }

  // ICM-20948
  if (icm_active) {

    entry.accelX = icm.getAccX();
    entry.accelY = icm.getAccY();
    entry.accelZ = icm.getAccZ();
  }

  // Ins CSV schreiben
  if (csvFile) {
    csvFile.print(entry.timestamp);
    csvFile.print(',');
    csvFile.print(entry.temp);
    csvFile.print(',');
    csvFile.print(entry.hum);
    csvFile.print(',');
    csvFile.print(entry.pres);
    csvFile.print(',');
    csvFile.print(entry.altitude);
    csvFile.print(',');
    csvFile.print(entry.accelX);
    csvFile.print(',');
    csvFile.print(entry.accelY);
    csvFile.print(',');
    csvFile.print(entry.accelZ);
    csvFile.print(',');
    csvFile.print(entry.voltage);
    csvFile.println();
    csvFile.flush();
  }
}

bool check_parachute() {

  bool zeroG = false;

  if (icm_active) {
    float totalAcc = sqrt(icm.getAccX() * icm.getAccX() + icm.getAccY() * icm.getAccY() + icm.getAccZ() * icm.getAccZ());
    if (totalAcc < 200) {
      zeroG = true;
    } else {
      zeroG = false;
    }
  }

  if (bme_active) {

    float altitude = bme.getAltitude();

    // Serial.println("Altitude: " + String(altitude) + "m");
    // Serial.println("Max Altitude: " + String(max_altitude) + "m");

    if (altitude < min_altitude) {
      min_altitude = altitude;
    }

    if (altitude > max_altitude) {
      max_altitude = altitude;
      return false;
    }

    if (zeroG && altitude < max_altitude - 0.1) {
      return true;
    }
  }
  return false;
}

void deploy_parachute() {
  servo.setAngle(90);
  last_parachute = millis();
  parachute_deployed = true;
  parachute_deploying = true;

  float height = max_altitude - min_altitude;
  display.show("Hoehe: \n" + String(height));
}


void loop() {

  uint32_t now = micros();
  if ((int32_t)(now - nextMicros) >= 0) {
    nextMicros += PUBLISH_INTERVAL * 1000;

    record();

    if (parachute_deployed) {
      if (parachute_deploying && millis() - last_parachute > 1000) {
        servo.setAngle(30);
        parachute_deploying = false;
      }
      if (millis() - last_parachute > 10000) {
        parachute_deployed = false;
        max_altitude = 0;
        min_altitude = 1000;
        Serial.println("Fallschirm zurückgesetzt");
        display.show("Launch ->");
      }
    }

    if (check_parachute()) {
      if (!parachute_deployed) {
        deploy_parachute();
      }
    }
  }
}

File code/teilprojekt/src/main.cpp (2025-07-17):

#include <Rakete_utility.h>

void setup()
{
  Serial.begin(115200);

  init();


  
  initWebserver();

  display.show("Launch -> ");
}


void loop()
{
  if ((micros() - nextMicros) >= 0)
  {
    nextMicros += PUBLISH_INTERVAL * 1000;
    // wird all 100 ms ausgefuehrt

    
  }

  if (parachute_progress && millis() - last_parachute > 1000)
  {
    // 1 Sekunde nach dem auslösen
   

  }

  if (parachute_deployed && millis() - last_parachute > 10000)
  {
    // 10 Sekunden nach dem auslösen
   
  
  }
}

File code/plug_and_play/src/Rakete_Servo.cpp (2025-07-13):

#include "Rakete_Servo.h"
#include "Arduino.h"

Rakete_Servo::Rakete_Servo( int servoPin_init) {
  servoPin = servoPin_init;
}

bool Rakete_Servo::init() {
  ledcSetup(channel, freq, resolution);
  ledcAttachPin(servoPin, channel);
  return true;
}

void Rakete_Servo::setAngle(int angle) {
  angle = constrain(angle, 0, 180);
  int pulse = map(angle, 0, 180, minPulseUs, maxPulseUs);
  uint32_t duty = pulseUsToDuty(pulse);
  ledcWrite(channel, duty);
}


uint32_t Rakete_Servo::pulseUsToDuty(int pulse_us) {
  float periodUs = 1e6 / freq;
  float dutyFraction = pulse_us / periodUs;
  return (uint32_t)(dutyFraction * ((1 << resolution) - 1));
}

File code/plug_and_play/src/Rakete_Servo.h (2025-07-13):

#pragma once

#include <Wire.h>

class Rakete_Servo {

public:
  Rakete_Servo(int servoPin_init);
  bool init();
  void setAngle(int angle);

private:

  uint32_t pulseUsToDuty(int pulse_us);
  int servoPin = 15;     // GPIO15
  const int freq = 50;         // 50 Hz for servos
  const int channel = 0;       // LEDC channel 0
  const int resolution = 16;   // 16-bit resolution
  const int minPulseUs = 500;  // Minimum pulse width in microseconds
  const int maxPulseUs = 2400; // Maximum pulse width in microseconds
};

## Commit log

2025-06-15 start programm
    [BOM-data_logger.csv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]
2025-06-17 working BNO086
    [flight_data_processed.csv]
2025-06-25 working battery
2025-06-27 adding servo and oled
2025-07-13 alles sauber
    [BOM-data_logger.csv, Rakete - Elektronikplatte.stl, Rakete - Finne1.stl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]
2025-07-13 cad pdf
2025-07-13 code sortiert
    [PodPad_baseplate.stl, PodPad_foot.stl, PodPad_hosebender.stl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]
